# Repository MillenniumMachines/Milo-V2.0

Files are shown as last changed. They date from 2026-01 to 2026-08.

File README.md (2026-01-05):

# Milo-V2
Millennium Machines Milo V2.0
<p align="center">
  
</p>
Millennium Machines Milo V2 is the next evolution of our open-source desktop CNC mill, building on the OpenBuilds MiniMill concept with major upgrades in size, rigidity, and customization. Designed for DIY builders, Milo V2 is More than capable of cutting aluminum (and steel if you're smart about it) while excelling at composites, woods, and plastics.

Milo V2 features a larger work area, fully redesigned plates and HOIs, simplified tramming, and magnetic way covers for easy maintenance. Builders can choose between leadscrews or ballscrews, select from two X-axis configurations, and benefit from new auto-adjusting anti-backlash nuts for long-term accuracy.

Milo V2 uses a moving-table X-axis, while its sibling Miley V2 features a stationary X-axis—both supported by the same LDO kit.

⚠️ IMPORTANT: ELECTRONICS NOT INCLUDED ⚠️

This repository does NOT include electronics.
To build the electronics system, you must use the [Universal Electronics Box](https://github.com/MillenniumMachines/Universal-Electronics-Box) repository.

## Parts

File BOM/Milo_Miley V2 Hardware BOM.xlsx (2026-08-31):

Category | Component | Standard | QTY | Note | Note 2 | Recommended | Alternative
Filament | Primary Color ABS/ASA |  | 3
Filament | Accent Color ABS/ASA |  | 1
Printed parts | Printed parts |  | 1
Fasteners | M5x8mm BHCS | ISO 7380-1 | 60 | (extra fatseners are included in this list) |  | ACCU (https://www.accu.co.uk/socket-button-screws/8146-SSB-M5-8-A2)
Fasteners | M5x10mm BHCS | ISO 7380-1 | 150 |  |  | ACCU (https://www.accu.co.uk/socket-button-screws/8147-SSB-M5-10-A2)
Fasteners | M5x12mm BHCS | ISO 7380-1 | 70 |  |  | ACCU (https://www.accu.co.uk/socket-button-screws/8148-SSB-M5-12-A2)
Fasteners | M5x30mm BHCS | ISO 7380-1 | 5 |  |  | ACCU (https://www.accu.co.uk/socket-button-screws/8155-SSB-M5-30-A2)
Fasteners | M5x25mm SHCS | ISO 4762 / DIN 912 | 6 |  |  | ACCU (https://www.accu.co.uk/cap-head-screws/10647-SSC-M5-25-A2)
Fasteners | M5x60mm SHCS | ISO 4762 / DIN 912 | 8 |  |  | ACCU (https://www.accu.co.uk/metric-cap-head-screws/2855-SSC-M5-60-A2)
Fasteners | M5x65mm SHCS | ISO 4762 / DIN 912 | 4 |  |  | ACCU (https://www.accu.co.uk/metric-cap-head-screws/2856-SSC-M5-65-A2)
Fasteners | M5x100mm SHCS | ISO 4762 / DIN 912 | 6 |  |  | ACCU (https://www.accu.co.uk/cap-head-screws/2861-SSC-M5-100-A2)
Fasteners | M6x10mm BHCS | ISO 7380-1 | 4
Fasteners | M5x6mm thread M6x4mm shoulder shoulder bolt | ISO 7379 | 2 |  |  | ACCU (https://www.accu.co.uk/metric-socket-shoulder-screws/10392-SSH-M5-4-A2)
Fasteners | M3x6mm SHCS | ISO 4762 / DIN 912 | 4 |  |  | ACCU (https://www.accu.co.uk/metric-cap-head-screws/3817-SSCF-M3-6-A2)
Fasteners | M3x10mm SHCS | ISO 4762 / DIN 912 | 150 |  |  | ACCU (https://www.accu.co.uk/cap-head-screws/3819-SSCF-M3-10-A2)
Fasteners | M3x20mm SHCS | ISO 4762 / DIN 912 | 6 |  |  | ACCU (https://www.accu.co.uk/cap-head-screws/2802-SSC-M3-20-A2)
Fasteners | M3x30mm SHCS | ISO 4762 / DIN 912 | 8 |  |  | ACCU (https://www.accu.co.uk/metric-cap-head-screws/2805-SSC-M3-30-A2)
Fasteners | M3x40mm SHCS | ISO 4762 / DIN 912 | 35 |  |  | ACCU (https://www.accu.co.uk/metric-cap-head-screws/2807-SSC-M3-40-A2)
Fasteners | M5 washer | ISO 7089 / DIN 125 | 6 | (only 4 are necessary but you can also use these on your FMJs in which case having another 60 will cover you) |  | ACCU (https://www.accu.co.uk/flat-washers/72492-HPW-M5-A2)
Fasteners | M3 washer | ISO 7089 / DIN 125 | 6 |  |  | ACCU (https://www.accu.co.uk/flat-washers/72482-HPW-M3-A2)
Fasteners | Disk spring washer 10.2mm ID 20mm OD | DIN 2093 | 9 | (0.6mm thick is recomended but thinner or thicker can also be used) |  | ACCU (https://www.accu.co.uk/disc-springs/430254-HDCW-10-2-20-0-6-A1)
Fasteners | M6x30mm Pin | ISO 2340 / DIN 7 | 2 | (we recommend getting 8 but you can get away with 2) |  | ACCU (https://www.accu.co.uk/dowel-pins/72561-HDP-10-30-A1)
Fasteners | M5x14mm or 15mm Pin | ISO 2340 / DIN 7 | 8 |  |  | ACCU (https://www.accu.co.uk/dowel-pins/395115-HDP-5-14-V1-A1)
Fasteners | M3x20mm Pin | ISO 2340 / DIN 7 | 8 |  |  | ACCU (https://www.accu.co.uk/dowel-pins/72643-HDP-3-20-A1)
Fasteners | M5x12 FHCS | ISO 10641 | 4 | (we recommend getting 16 but you can get away with 4) |  | ACCU (https://www.accu.co.uk/countersunk-socket-head-screws/5463-SSK-M5-12-A2)
Fasteners | M3x6 FHCS | ISO 10642 | 15 |  |  | ACCU (https://www.accu.co.uk/countersunk-socket-head-screws/5595-SSK-M3-6-A4)
Fasteners | M5 Grease Nipple | DIN 71412 | 3 |  |  | Aliexpress (https://s.click.aliexpress.com/e/_oE2i5VE)
Fasteners | M5 heated inserts |  | 30 |  |  | CNC KITCHEN (https://cnckitchen.store/products/heat-set-insert-m5-x-5-8-short-version-50-pieces)
Fasteners | M3 heated inserts |  | 80 | (Choose between voron style or cnc kitchen style inserts) |  | CNC KITCHEN (https://cnckitchen.store/products/heat-set-insert-m3-x-3-short-version-100-pieces) | Aliexpress (https://s.click.aliexpress.com/e/_ol2Yb5O)
Fasteners | M5 roll in T nut |  | 150 |  |  | Aliexpress (https://www.aliexpress.com/item/1005004082080953.html)
Fasteners | M3 roll in T nut |  | 70 |  |  | Aliexpress (https://www.aliexpress.com/item/1005004082080953.html)
Fasteners | M3x5mm Grub screw | ISO 4026 / DIN 913 | 8 |  |  | ACCU (https://www.accu.co.uk/flat-point-set-screws/4513-SSF-M3-5-A2)
Fasteners | M2x10 self tapping screw for plastics |  | 4 | (these are only if you choose to use a microswitch for the Y axis instead of an inductive probe) |  | Aliexpress (https://s.click.aliexpress.com/e/_omMaO8U)
Tool setter hardware | 5x7x8 Sleeve Bearing |  | 2 | (everything here can be bought together, in a hartK sexbolt kit) |  | Aliexpress (https://s.click.aliexpress.com/e/_okHNgoY)
Tool setter hardware | M4x6mm SHCS | ISO 4762 / DIN 912 | 1
Tool setter hardware | M5x20 sex-bolt |  | 1
Tool setter hardware | M2x10 self tapping screw for plastics |  | 4
Electronics | HartK sexbolt PCB |  | 1
Frame | Openbuilds C-Beam profile extrusion 315mm |  | 2 |  |  | Ooznest (https://ooznest.co.uk/product/c-beam-linear-rail-cut-to-size/)
Frame | Openbuilds C-Beam profile extrusion 120mm |  | 1 |  |  | Ooznest (https://ooznest.co.uk/product/c-beam-linear-rail-cut-to-size/)
Frame | Openbuilds C-Beam profile extrusion 255mm |  | 2 |  |  | Ooznest (https://ooznest.co.uk/product/c-beam-linear-rail-cut-to-size/)
Frame | Openbuilds C-Beam profile extrusion 550mm |  | 1 |  |  | Ooznest (https://ooznest.co.uk/product/c-beam-linear-rail-cut-to-size/)
Frame | Openbuilds C-Beam profile extrusion 540mm |  | 1 |  |  | Ooznest (https://ooznest.co.uk/product/c-beam-linear-rail-cut-to-size/)
Frame | 2020 V-slot extrusion 315mm |  | 2 |  |  | Ooznest (https://ooznest.co.uk/product/v-slot-linear-rail-20x20mm-cut-to-size/)
Frame | 2060 V-slot extrusion 550mm |  | 2 |  |  | Ooznest (https://ooznest.co.uk/product/20x60mm-t-v-slot-aluminium-extrusion-profile-black-cut-to-size/)
Frame | 2080 V-slot extrusion 40mm |  | 2 |  |  | Ooznest (https://ooznest.co.uk/product/v-slot-linear-rail-20x80mm-cut-to-size/)
Frame | 2080 V-slot extrusion 120mm |  | 2 |  |  | Ooznest (https://ooznest.co.uk/product/v-slot-linear-rail-20x80mm-cut-to-size/)
Frame | 2080 V-slot extrusion 440mm |  | 1 |  |  | Ooznest (https://ooznest.co.uk/product/v-slot-linear-rail-20x80mm-cut-to-size/)
Motion | 6082Z deep groove ball bearing |  | 9 |  |  | Aliexpress (https://s.click.aliexpress.com/e/_9fU0np)
Motion | F8-16M thrust bearing |  | 6 |  |  | Aliexpress (https://s.click.aliexpress.com/e/_oF9iZs0)
Motion | Spider or rigid coupler 8mm to 6.35mm (1/4 inch) |  | 3 |  |  | Aliexpress (https://s.click.aliexpress.com/e/_AFwDq7)
Motion | MGN15 rail 550mm |  | 2 | (in total you will need 12 MGN15C carriages) |  | Aliexpress (https://s.click.aliexpress.com/e/_ooDrApW)
Motion | MGN15 rail 250mm |  | 2 |  |  | Aliexpress (https://s.click.aliexpress.com/e/_ooDrApW)
Motion | MGN15 rail 400mm |  | 2 |  |  | Aliexpress (https://s.click.aliexpress.com/e/_ooDrApW)
Motion | TR8x8 leadscrew/ SFK 0802 ballscrew 600mm |  | 2 | (we recommend the leadscrews over the the ballscrews but decide for yourself) | (if you choose ballscrews get ones without machined ends) | Leadscrews | Ballscrews (https://s.click.aliexpress.com/e/_ok8oT3Q)
Motion | TR8x8 leadscrew/ SFK 0802 ballscrew 300mm |  | 1 | (we recommend the leadscrews over the the ballscrews but decide for yourself) | (if you choose ballscrews get ones without machined ends) | Leadscrews | Ballscrews (https://s.click.aliexpress.com/e/_ok8oT3Q)
Motion | Brass Tr8x8 Leadscrew nuts |  | 6 | (these are only used if you decide to use leadscrews and not ballscrews) | (if you choose ballscrews get ones without machined ends) | Leadscrews | Ballscrews (https://s.click.aliexpress.com/e/_ok8oT3Q)
Motion | TR8x8 hexagonal lock nut |  | 6 | (these are only used if you decide to use leadscrews and not ballscrews) |  | Aliexpress (https://www.aliexpress.com/item/1005002600044383.html)
Motion | 8mm Bore double split locking collar |  | 6 |  |  | Aliexpress (https://s.click.aliexpress.com/e/_onG3vYs)
Motion | GT2 40T (6mm wide) Pulley (8mm bore) |  | 1 | (this is a requirement for building miley but can be skipped for Milo) |  | Aliexpress (https://s.click.aliexpress.com/e/_oFnbUUc)
Motion | GT2 40T (6mm wide) Pulley (6.35mm bore) |  | 1 | (this is a requirement for building miley but can be skipped for Milo)
Motion | 200mm GT2 closed loop belt |  | 1 | (this is a requirement for building miley but can be skipped for Milo) |  | Aliexpress (https://s.click.aliexpress.com/e/_ASjMnD)
Electronics | Nema 23 56mm stepper motor 2.8A |  | 1
Electronics | Nema 23 86mm stepper motor 2.8A |  | 2
Electronics | LJ8A3-2-Z/AY inductive probe NC |  | 3 |  |  | Aliexpress (https://s.click.aliexpress.com/e/_oBxHusk)
Electronics | Omron DF2-01L microswitch |  | 1 | (this is only if you choose to use a microswitch for the Y axis instead of an inductive probe) |  | Aliexpress (https://s.click.aliexpress.com/e/_oFxia8c)
Electronics | 3 axis 3D touch probe |  | 1 | (optional but recommended) |  | Aliexpress (https://s.click.aliexpress.com/e/_ol2mwqs)
Hardware | 10x11 Cable Chain - Openable (1m) |  | 2 |  |  | Aliexpress (https://s.click.aliexpress.com/e/_AkGI1l)
Hardware | 8x3 Neodymium magnet |  | 30
Hardware | 90 degree corner connector |  | 30 |  |  | Aliexpress (https://www.aliexpress.com/item/1005003308136627.html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)
Hardware | Cloth bellows |  | 1 | (this will need to be cut to 110mm wide) |  | Aliexpress (https://s.click.aliexpress.com/e/_olkqRvK)
CNC machined parts | XY-joiner-plate |  | 1
CNC machined parts | Fixated-V2 |  | 1 | (this is a requirement for building miley but can be skipped for Milo)
CNC machined parts | Z mounting plate |  | 1
CNC machined parts | Z Tram Plate |  | 1
CNC machined parts | HOI front |  | 1 or 2 | (these are optional and you can get away with only one if you need to. choose between 65 and 80mm versions)
CNC machined parts | HOI rear |  | 2 or 2 | (these are optional and you can get away with only one if you need to. choose between 65 and 80mm versions)
Misc | Epoxy Resin 1L |  | 1 | (optional)
Misc | Granite Sand |  | 1 | (optional)
Misc | Lithium Grease |  | 1 | For linear bearings and screws
Misc | VHB tape any size >10mm |  | 1

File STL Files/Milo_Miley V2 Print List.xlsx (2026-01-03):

Print Setting Name | Wall Count | Top/Bottom layers | Nozzle Size | Layer Height | Infill % | Infill Type
A (aesthetic) | 3 | 5 | 0.4mm | 0.2mm | 20 | Gyroid/Cubic
SS (semi structural) | 4 | 5 | 0.4mm | 0.2mm | 25 | Gyroid/Cubic
S (structural) | 6 | 6 | 0.4mm | 0.2mm | 45 | Gyroid/Cubic
Part Category | Part Name | Print Setting | Material | Quantity | Accent color Y/N | Note
Leadscrew-Ballscrew-Nuts | Leadscrew-ThrED-AB-Block-x3-S | S | ABS | 3 | N | All parts that use M3 heat isnerts either use Voron spec or CNC Kitchen spec use the parts marked with the spec youre using
Leadscrew-Ballscrew-Nuts | Leadscrew-ThrED-AB-Block-Voron-Inserts-x3-S | S | ABS | 3 | N
Leadscrew-Ballscrew-Nuts | Leadscrew-ThrED-Compression-plate-x3-S | S | ABS | 3 | N
Leadscrew-Ballscrew-Nuts | Leadscrew-ThrED-Compression-plate-Voron-Inserts-x3-S | S | ABS | 3 | N
Leadscrew-Ballscrew-Nuts | SFK-Ballscrew-AB-Block-x3-S | S | ABS | 3 | N
Leadscrew-Ballscrew-Nuts | SFK-Ballscrew-AB-Block-Voron-Inserts-x3-S | S | ABS | 3 | N
Leadscrew-Ballscrew-Nuts | Ballnut-plate-x3-S | S | ABS | 3 | N
Leadscrew-Ballscrew-Nuts | Ballnut-plate-Voron-Inserts-x3-S | S | ABS | 3 | N
Floating-Bearings | [a]-Internal-Axis-Floating-Bearing-Block-x3-S | S | ABS | 3 | Y
Floating-Bearings | [a]-Interna-Axis-Floating-Bearing-Block-Faceplate-A-x3-S | S | ABS | 3 | Y
Floating-Bearings | [a]-Interna-Axis-Floating-Bearing-Block-Faceplate-B-x3-S | S | ABS | 3 | Y
Floating-Bearings | Internal-Axis-Floating-Bearing-Block-Faceplate-A-Voron-Inserts-x3-S | S | ABS | 3 | N
X-Axis-Milo | X-Axis-Motor-Mount-Voron-Inserts-x1-SS | SS | ABS | 1 | N | Pick Milo parts or Miley parts not both
X-Axis-Milo | X-Axis-Motor-Mount-x1-SS | SS | ABS | 1 | N
X-Axis-Milo | Table-Support-Center-x2-SS | SS | ABS | 2 | N
X-Axis-Milo | Table-Support-End-x4-SS | SS | ABS | 4 | N
X-Axis-Milo | [a]-X-Bearing-Block-Insert-x1-SS | SS | ABS | 1 | Y
X-Axis-Milo | X-Axis-Bearing-Block-x1-SS | SS | ABS | 1 | N
X-Axis-Milo | X-Axis-Bearing-Block-x1-SS | SS | ABS | 1 | N
X-Axis-Miley | X-Axis-Motor-Mount-Voron-Inserts-x1-SS | SS | ABS | 1 | N
X-Axis-Miley | X-Axis-Motor-Mount-x1-SS | SS | ABS | 1 | N
X-Axis-Miley | Table-Support-Center-x2-SS | SS | ABS | 2 | N
X-Axis-Miley | Table-Support-End-x4-SS | SS | ABS | 4 | N
X-Axis-Miley | [a]-X-Bearing-Block-Insert-x1-SS | SS | ABS | 1 | Y
X-Axis-Miley | X-Axis-Bearing-Block-x1-SS | SS | ABS | 1 | N
X-Axis-Miley | X-Axis-Bearing-Block-x1-SS | SS | ABS | 1 | N
Y-Axis | Y-Endstop-Microswitch-x1-SS | SS | ABS | 1 | N
Y-Axis | Y-Endstop-Microswitch-Voron-Inserts-x1-SS | SS | ABS | 1 | N
Y-Axis | Y-Endstop-x1-SS | SS | ABS | 1 | N
Y-Axis | Y-Endstop-Voron-Inserts-x1-SS | SS | ABS | 1 | N
Y-Axis | Dust-cover-x1-A | A | ABS | 1 | N
Y-Axis | Dust-cover-Mirror-x1-A | A | ABS | 1 | N
Y-Axis | Y-Axis-Hold-Down-A1-x1-SS | SS | ABS | 1 | N
Y-Axis | Y-Axis-Hold-Down-A2-x1-SS | SS | ABS | 1 | N
Y-Axis | Y-Axis-Hold-Down-B-x4-SS | SS | ABS | 4 | N
Y-Axis | Y-Axis-Hold-Down-C1-x1-SS | SS | ABS | 1 | N
Y-Axis | Y-Axis-Hold-Down-C2-x1-SS | SS | ABS | 1 | N
Y-Axis | Y-Axis-Hold-Down-D1-x1-SS | SS | ABS | 1 | N
Y-Axis | Y-Axis-Hold-Down-D2-x1-SS | SS | ABS | 1 | N
Y-Axis | Y-Axis-Motor-Mount-A-x1-SS | SS | ABS | 1 | N
Y-Axis | Y-Axis-Motor-Mount-B-x1-SS | SS | ABS | 1 | N
Y-Axis | Y-Axis-Motor-Mount-Unibody-x1-SS | SS | ABS | 1 | N
Y-Axis | [a]-Bellow-Attachment-Plate-x2-A | A | ABS | 2 | Y
Y-Axis | [a]-Y-Axis-Bellow-Column-Mag-Mount-x1-A | A | ABS | 1 | Y
Y-Axis | [a]-Y-Axis-Bellow-Plate-Mag-Mount-x1-A | A | ABS | 1 | Y
Y-Axis | [a]-Way-Cover-Magnet-Lock-x1-A | A | ABS | 1 | Y
Y-Axis | [a]-Way-Cover-Y-Front-A-x1-A | A | ABS | 1 | Y
Y-Axis | [a]-Way-Cover-Y-Front-B-x1-A | A | ABS | 1 | Y
Y-Axis | [a]-Way-Cover-Y-Front-C-x1-A | A | ABS | 1 | Y
Y-Axis | [a]-Way-Cover-Y-Front-D-x1-A | A | ABS | 1 | Y
Y-Axis | [a]-Way-Cover-Y-Front-E-x1-A | A | ABS | 1 | Y
Y-Axis | [a]-Way-Cover-Y-Front-F-x1-A | A | ABS | 1 | Y
Y-Axis | [a]-Way-Cover-Y-Front-G-x1-A | A | ABS | 1 | Y
Y-Axis | [a]-Y-Bearing-Block-x1-SS | SS | ABS | 1 | Y
Y-Axis | [a]-Y-Bearing-Block-Insert-x1-SS | SS | ABS | 1 | Y
Y-Axis | [a]-Y-Bearing-Block-Voron-Inserts-x1-SS | SS | ABS | 1 | Y
Z-Axis | [a]-Z-Axis-Bearing-Block-x1-S | S | ABS | 1 | Y
Z-Axis | [a]-Z-Axis-Bearing-Block-Voron-Inserts-x1-S | S | ABS | 1 | Y
Z-Axis | Z-Bearing-Block-Insert-x1-S | S | ABS | 1 | N
Z-Axis | Column-Ballast-x2-A | A | ABS | 2 | N
Z-Axis | Rear-Column-Chain -Anchor-Faceplate-x1-A | A | ABS | 1 | N
Z-Axis | Rear-Column-Chain-Anchor-x1-A | A | ABS | 1 | N
Z-Axis | Rear-Column-Chain-Anchor-Voron-Inserts-x1-A | A | ABS | 1 | N
Z-Axis | Z-Axis-Rear-Cable-Run-x1-SS | SS | ABS | 1 | N
Z-Axis | FMJ-Printed-A-x2-S | S | ABS | 2 | N | Not recommended
Z-Axis | FMJ-Printed-B-x2-S | S | ABS | 2 | N | Not recommended
Z-Axis | FMJ-Printed-C-x2-S | S | ABS | 2 | N | Not recommended
Spindle-Mounts | Logo-insert-x1-A | A | ABS | 1 | N
Spindle-Mounts | [a]-65mm-Spindle-Mount-Front-x1-S | S | ABS | 1 | Y
Spindle-Mounts | [a]-65mm-HOI-Half-Plate-Spindle-Mount-Front-printed-x1-SS | SS | ABS | 1 | Y
Spindle-Mounts | [a]-65mm-HOI-Full-Plate-Spindle-Mount-Front-printed-x1-A | A | ABS | 1 | Y
Spindle-Mounts | 65mm-Spindle-Mount-Back-x1-S | S | ABS | 1 | N
Spindle-Mounts | 65mm-HOI-Half-Plate-Spindle-Mount-Back-printed-x1-SS | SS | ABS | 1 | N
Spindle-Mounts | 65mm-HOI-Half-Plate-Spindle-Mount-Back-printed-x1-SS | A | ABS | 1 | N
Spindle-Mounts | [a]-80mm-Spindle-Mount-Front-x1-S | S | ABS | 1 | Y
Spindle-Mounts | [a]-80mm-HOI-Half-Plate-Spindle-Mount-Front-printed-x1-SS | SS | ABS | 1 | Y
Spindle-Mounts | [a]80mm-HOI-Full-Plate-Spindle-Mount-Front-printed-x1-A | A | ABS | 1 | Y
Spindle-Mounts | 80mm-Spindle-Mount-Back-x1-S | S | ABS | 1 | N
Spindle-Mounts | 80mm-HOI-Half-Plate-Spindle-Mount-Back-printed-x1-SS | SS | ABS | 1 | N
Spindle-Mounts | 80mm-HOI-Half-Plate-Spindle-Mount-Back-printed-x1-SS | A | ABS | 1 | N
Miscelaneous | Toolsetter-Housing-S | S | ABS | 1 | N
Miscelaneous | Fixated-Centering-Tool-x2-A | A | ABS | 2 | N | These can work as chip covers on milo later
Miscelaneous | Fixated-M6-Plug-x140-A | A | ABS | 140 | N | Print as many as you need 140 just covers all the holes
Miscelaneous | Fixated-Mounting-Slot-Cover-x3-A | A | ABS | 3 | N
Miscelaneous | Milo-Fixated-Carriage-Hole-Plug-x20-A | A | ABS | 20 | N | Don't print these if you're building miley

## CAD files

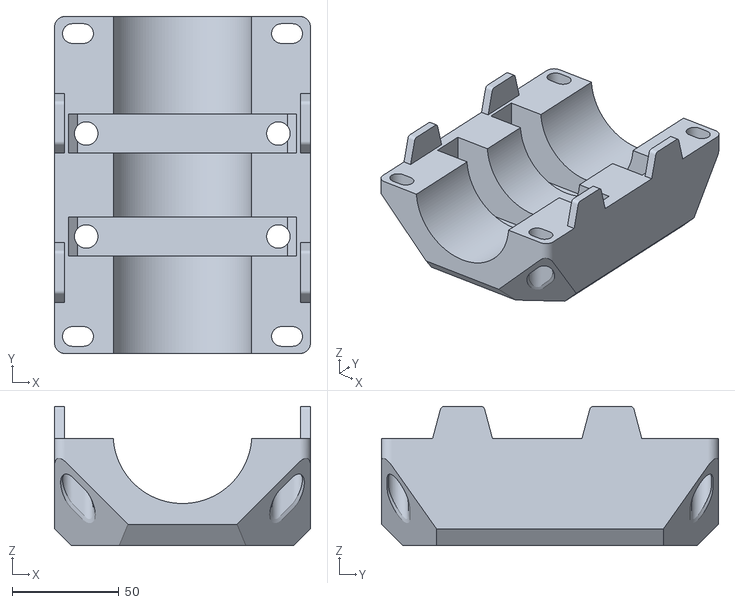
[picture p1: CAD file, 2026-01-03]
STL Files/Spindle-Mounts/65mm-Spindle-Mounts/[a]-65mm-HOI-Full-Plate-Spindle-Mount-Front-printed-x1-A.stl
120.0 x 158.0 x 65.4

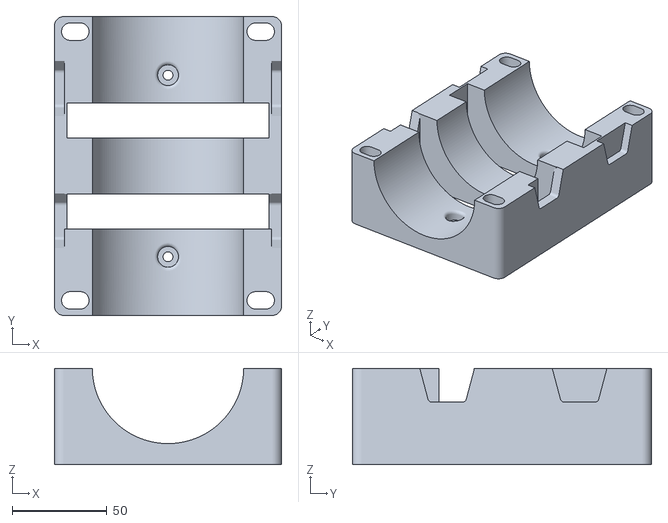
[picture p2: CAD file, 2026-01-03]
STL Files/Spindle-Mounts/80mm-Spindle-Mounts/80mm-HOI-Full-Plate-Spindle-Mount-Back-printed-x1-A.stl
120.0 x 158.0 x 50.9

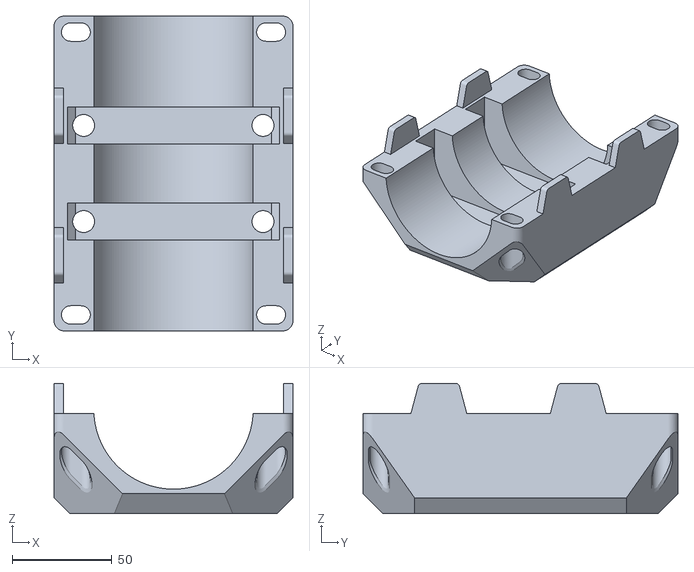
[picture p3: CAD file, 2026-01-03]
STL Files/Spindle-Mounts/80mm-Spindle-Mounts/[a]-80mm-HOI-Full-Plate-Spindle-Mount-Front-printed-x1-A.stl
120.0 x 158.0 x 65.4

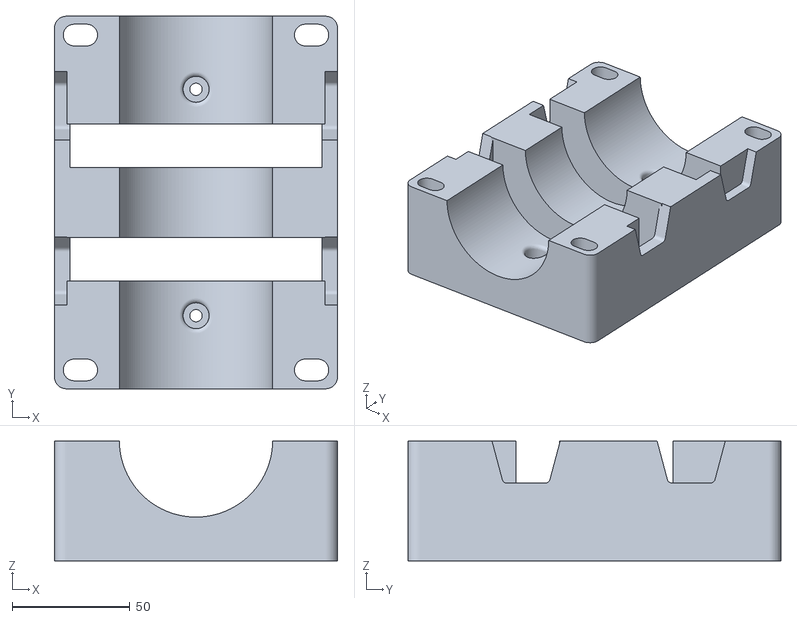
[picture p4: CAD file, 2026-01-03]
STL Files/Spindle-Mounts/65mm-Spindle-Mounts/65mm-HOI-Full-Plate-Spindle-Mount-Back-printed-x1-A.stl
120.0 x 158.0 x 50.9

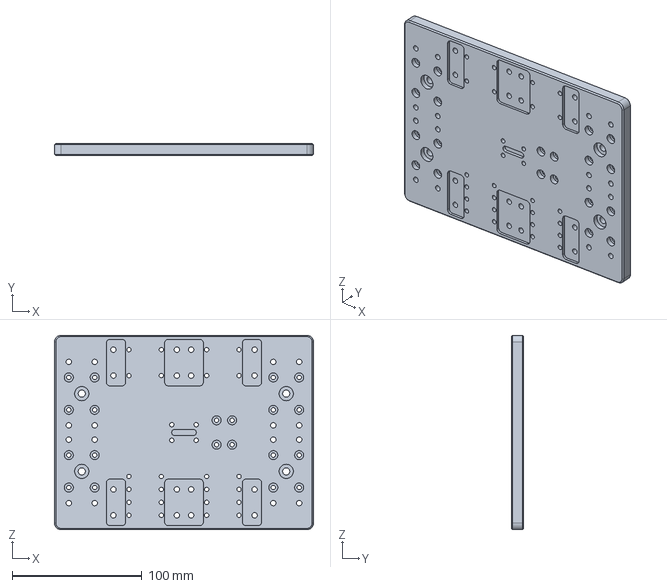
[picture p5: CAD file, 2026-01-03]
CNC Parts/X-to-Y-Joiner-Plate-Manufacturing-Model.step
200.0 x 9.60 x 150.0 mm

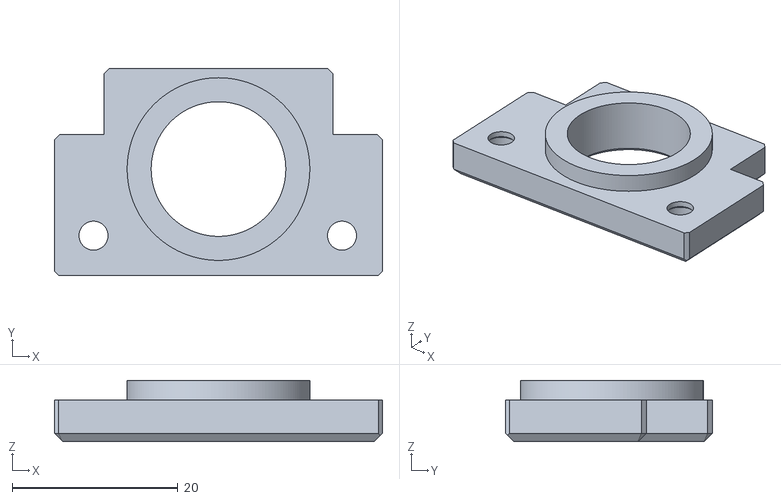
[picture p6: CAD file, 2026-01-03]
STL Files/Floating-Bearings/[a]-Interna-Axis-Floating-Bearing-Block-Faceplate-A-x3-S.stl
39.6 x 25.0 x 7.40

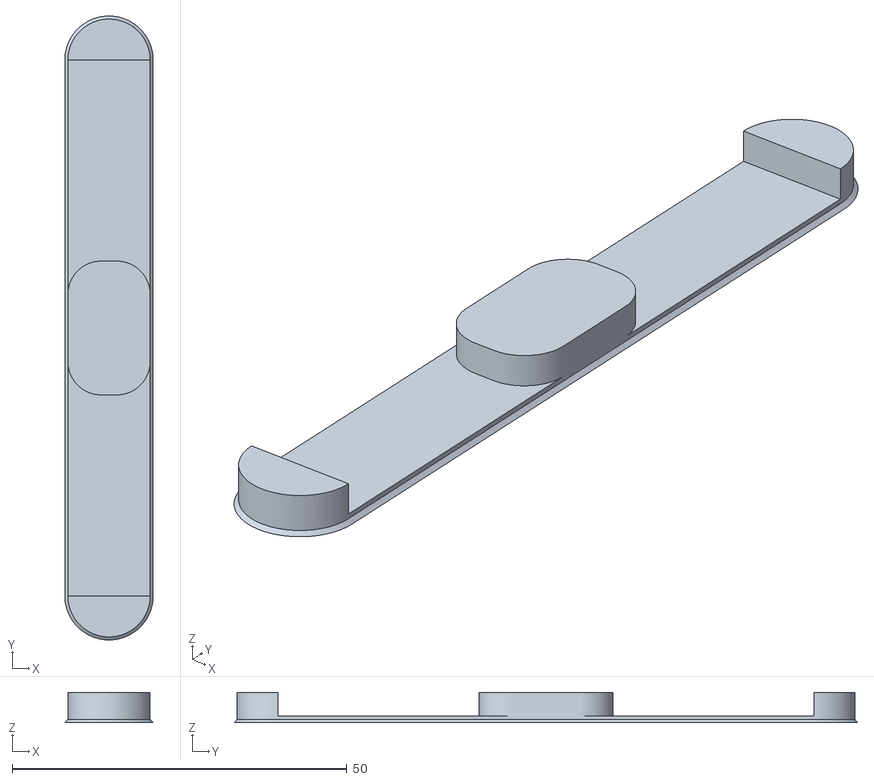
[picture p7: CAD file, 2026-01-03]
STL Files/Miscelaneous/Fixated/Fixated-Mounting-Slot-Cover-x3-A.stl
13.2 x 93.2 x 4.50

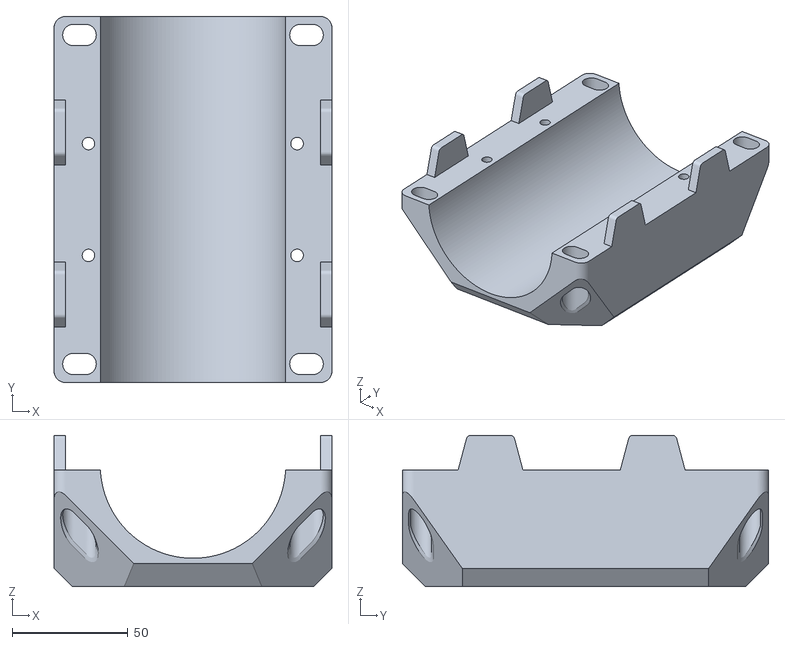
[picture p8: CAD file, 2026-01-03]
STL Files/Spindle-Mounts/80mm-Spindle-Mounts/[a]-80mm-Spindle-Mount-Front-x1-S.stl
120.0 x 158.0 x 65.4

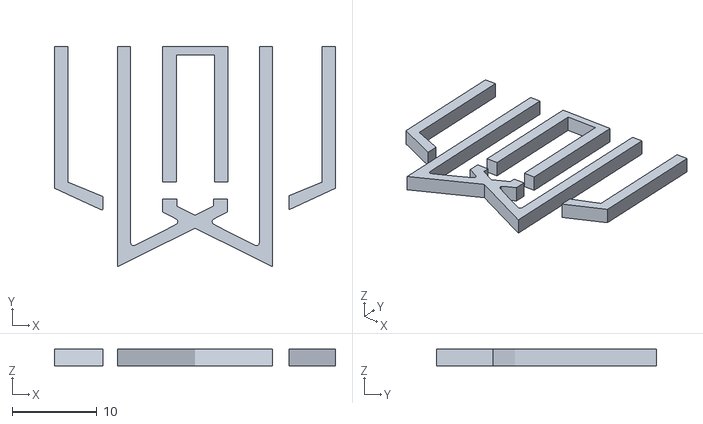
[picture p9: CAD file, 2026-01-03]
STL Files/Spindle-Mounts/Logo-insert-x1-A.stl
33.2 x 26.1 x 2.00

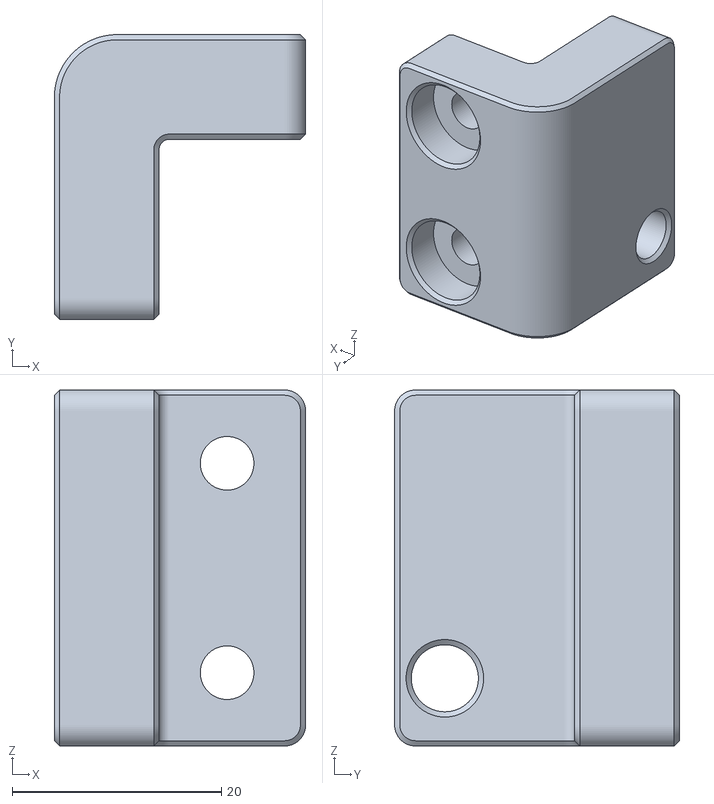
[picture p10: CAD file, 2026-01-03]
STL Files/Tools/Tram-Aid.stl
24.0 x 27.2 x 34.0

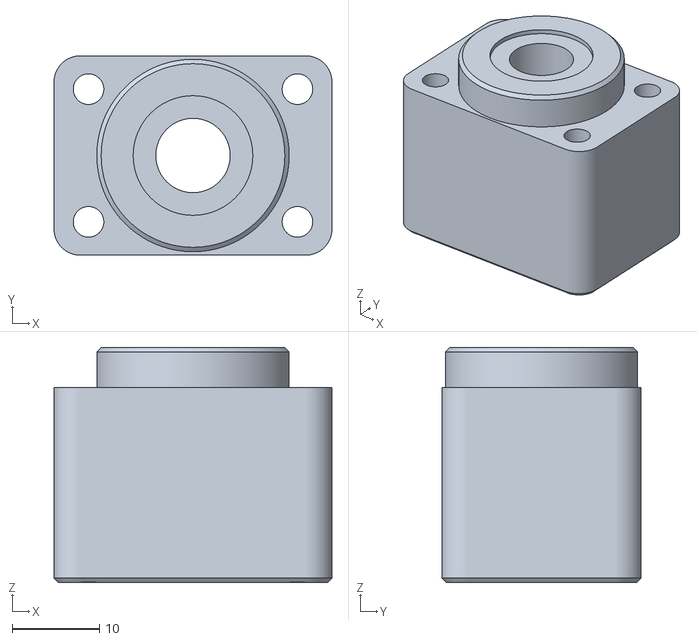
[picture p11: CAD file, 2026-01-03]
STL Files/X-Axis-Miley/Bearing-Block/[a]-X-Bearing-Block-Insert-x1-SS.stl
31.8 x 22.8 x 26.9

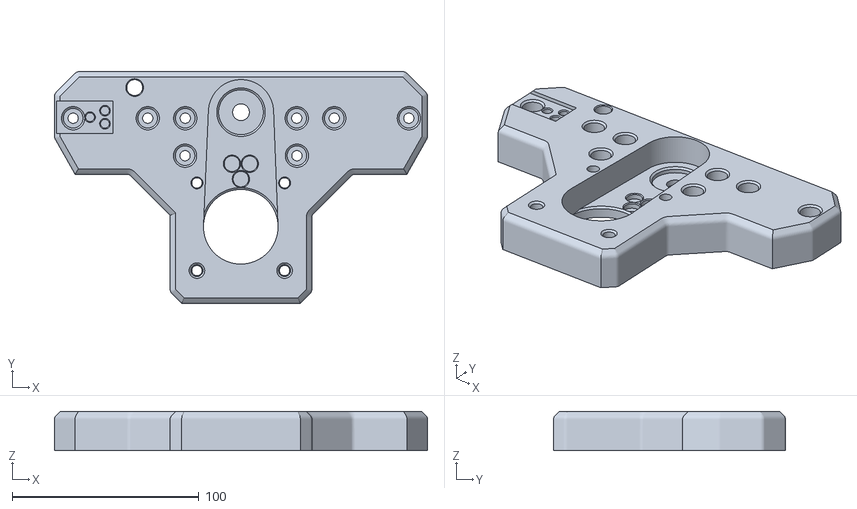
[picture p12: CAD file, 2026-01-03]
STL Files/X-Axis-Miley/Motor-Mount/X-Axis-Motor-Mount-Voron-Inserts-x1-SS.stl
200.0 x 124.3 x 21.0

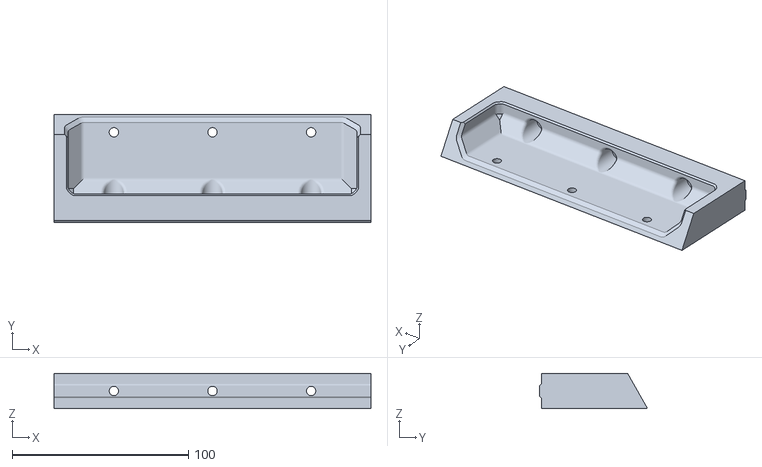
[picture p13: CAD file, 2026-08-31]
STL Files/X-Axis-Miley/Table-Supports/Table-Support-Center-X2-SS.stl
180.0 x 61.1 x 20.0

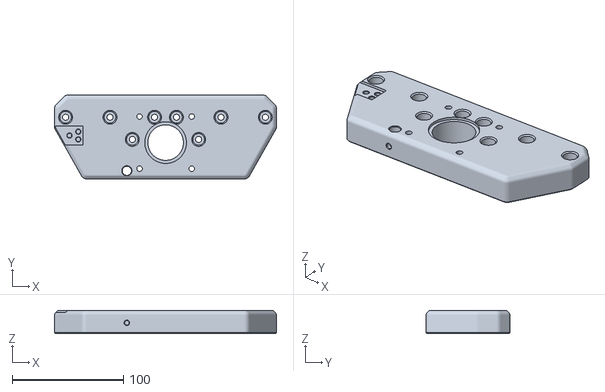
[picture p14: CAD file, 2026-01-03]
STL Files/X-Axis-Milo/Motor-Mount/X-Axis-Motor-Mount-x1-SS.stl
200.0 x 75.6 x 21.0

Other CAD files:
STL Files/X-Axis-Milo/Table-Supports/Table-Support-End-x4-SS.stl
STL Files/X-Axis-Milo/X-Bearing-Block/X-Axis-Bearing-Block-x1-SS.stl
STL Files/Y-Axis/End-Stop-Mount/Y-Endstop-x1-SS.stl
STL Files/Y-Axis/Hold-Downs/Y-Axis-Hold-Down-B-x4-SS.stl
CNC Parts/65mm-HOI-Spindle-Mount-Back-Machined.step
CNC Parts/65mm-HOI-Spindle-Mount-Front-Machined.step
CNC Parts/80mm-HOI-Spindle-Mount-Back-Machined.step
CNC Parts/80mm-HOI-Spindle-Mount-Front-Machined.step
CNC Parts/Blank-Tram-Plate-MANUFACTURING-MODEL.step
CNC Parts/FMJ-V2.step
CNC Parts/Tram-Plate-MANUFACTURING-MODEL.step
CNC Parts/Z-Mounting-Plate-MANUFACTURING-MODEL.step
STL Files/Floating-Bearings/Internal-Axis-Floating-Bearing-Block-x3-S.stl
STL Files/Floating-Bearings/[a]-Interna-Axis-Floating-Bearing-Block-Faceplate-B-x3-S.stl
STL Files/Floating-Bearings/[a]-Internal-Axis-Floating-Bearing-Block-Faceplate-A-Voron-Inserts-x3-S.stl
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

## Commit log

2024-10-08 Add initial wiring diagram
    Add modular cabling diagrams and generator, using WireViz
    Move more templates to common file
    Add generated HTML wiring diagrams
    Rename cabling directory
    [milo-v2.0-motors-endstops-probes.yaml]
2024-10-15 Switch power socket to C20, rename wiring folder
    [milo-v2.0-motors-endstops-probes.yaml]
2026-01-03 Initial upload of release material
    [65mm-HOI-Full-Plate-Spindle-Mount-Back-printed-x1-A.stl, 65mm-HOI-Half-Plate-Spindle-Mount-Back-printed-x1-SS.stl, 65mm-HOI-Spindle-Mount-Back-Machined.step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]
2026-01-03 Remove wiring info
    [milo-v2.0-motors-endstops-probes.yaml]
2026-05-16 Spelling correction
    [Fixated-Centering-Tool-x2-A.stl, Fixated-Mounting-Slot-Cover-x3-A.stl, Milo-Fixated-Carriage-Hole-Plug-x20-A.stl]
2026-05-16 Add optional Fixated end covers and Y coupler cover
    [Fixated-end-plate-x2-A.stl, Rail-Alignment-Guide.stl, Y-Axis-Coupler-Cover-x1-A.stl]
2026-06-03 Upload LDO spindle mount files
    [LDO-Spindle-Mount-Back-Bottom-x1-A.stl, LDO-Spindle-Mount-Back-Top-x1-A.stl, [a]-LDO-80mm-Spindle-Mount-Front-x1-A.stl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]
2026-06-05 Correct LDO spindle mount back heat insert size
    [LDO-Spindle-Mount-Back-Bottom-x1-A.stl, LDO-Spindle-Mount-Back-Top-x1-A.stl]
2026-06-11 Note about bellows needing to be cut to length. Added T-Nuts to ZY Assembly on page 41. Show correct LDO spindle front cover on page 115.
2026-07-29 Fix for incorrect STL for Miley X axis table support
    [Table-Support-Center-X2-SS.stl]
2026-07-29 bom fixes for inaccurate comment, typos
    [Milo_Miley V2 Hardware BOM.xlsx]
2026-08-31 Correct placement of LDO spindle mount backs
    [LDO-Spindle-Mount-Back-Bottom-x1-A.stl, LDO-Spindle-Mount-Back-Top-x1-A.stl]
2026-10-12 Update [a]-LDO-80mm-Spindle-Mount-Front-x1-A.stl
    Correct orientation of LDO spindle front
2026-10-12 Update [mc]-LDO-80mm-Spindle-Mount-Front-x1-A.step
    Update orientation of LDO multicolor spindle front
2026-10-27 Updated X-axis motor mounts
2026-11-06 Updates to correct naming of some parts, add missing misc parts, add missing motor mount part, add suggested filament reqs
